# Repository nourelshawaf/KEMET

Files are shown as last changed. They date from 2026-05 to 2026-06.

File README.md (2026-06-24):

# KEMET — Autonomous Maze-Solving Robot

> Embedded C++ · ESP32 + Raspberry Pi Pico · RFID navigation · Encoder-based motor control

Built for the **Óbuda University Labyrinth Competition**. KEMET navigates a maze fully autonomously — no remote control, no external compute. It reads RFID tags at intersections, drives between walls using IR and ToF sensors, and executes turns with encoder-closed-loop feedback.

---

## Demo

> Video coming after first successful maze run.
> 
> Phase 1 preview: encoder-based straight driving + 90° pivot calibration sequence (Straight → Right → Right → Left → Left, repeating).

---

## What It Does

| Capability | Implementation |
|---|---|
| Navigate maze intersections | RC522 RFID reader decodes `LEFT` / `RIGHT` / `DEAD END` tags |
| Drive straight without drift | Encoder pulse comparison between left and right wheel; software trim |
| Execute accurate 90° turns | Encoder-counted pivot; separate left/right calibration constants |
| Detect walls | VL53L1X ToF (front) + 4× Sharp IR (sides) |
| Stop before hitting walls | Front ToF threshold at 150 mm |
| Distributed control | ESP32 handles sensing + logic; Pico handles motors over UART |

---

## Architecture

```
┌─────────────────────────────────┐     UART 115200     ┌──────────────────────┐
│            ESP32                │ ─── "FWD\n" ──────► │   Raspberry Pi Pico  │
│  • RFID (RC522, SPI)            │ ◄── "OK\n" ──────── │  • PWM motor drive   │
│  • ToF wall sensor (VL53L1X)    │                      │  • Encoder counting  │
│  • 4× Sharp IR (analog ADC)     │                      │  • 90° pivot control │
│  • Maze graph + path logic      │                      │  • Drift correction  │
└─────────────────────────────────┘                      └──────────────────────┘
         │                                                        │
         └───────────── TB6612FNG motor driver ◄──────────────────┘
                              │
                    Left motor · Right motor
                   (HC-89 encoders, 35 PPR)
```

**Power:** 2S Li-ion → main switch → buck converter (5 V logic) + direct to motor rail (7.2–8.4 V)

---

## Hardware

| Component | Part |
|---|---|
| Navigation controller | ESP32 (ESP-WROOM-32) |
| Motor controller | Raspberry Pi Pico |
| Motor driver | TB6612FNG |
| Motors | 2× DC gear motors, Ø 37 mm wheels |
| Wheel encoders | 2× HC-89 optical (35 pulses/rev, measured) |
| RFID reader | RC522 — **3.3 V only** |
| Front distance | VL53L1X Time-of-Flight |
| Side distance | 4× Sharp GP2Y0A51SK0F analog IR |
| Power | 2S Li-ion + step-down buck converter |

**Competition constraint:** robot must fit inside `280 × 280 × 150 mm`, operate with no external communication.

---

## Repository Structure

```
KEMET/
├── Code/
│   ├── Pico/motor_control/          ← Phase 1: encoder-based motor calibration (.ino)
│   └── ESP32-mapper/INCLUDE/        ← Maze graph types, sensor manager, pin config (.h)
├── Hardware/
│   ├── wiring_diagrams/             ← Full pin-to-pin tables for V1 and V2
│   ├── schematics/                  ← EasyEDA schematic JSON + generator script
│   └── bill_of_materials.md
├── Docs/
│   ├── system_architecture.md
│   ├── motor_control.md
│   ├── rfid_navigation.md
│   ├── calibration.md
│   ├── wall_following.md
│   ├── troubleshooting.md
│   └── prototypes/prototype_v1.md · prototype_v2.md
├── Tests/
│   ├── turn_tests/
│   ├── straight_line_tests/
│   └── ...
└── Media/photos/
```

---

## How to Run (Phase 1 — Motor Calibration)

**Hardware required:** Raspberry Pi Pico + TB6612FNG + 2 motors + 2 HC-89 encoders. No ESP32 needed for Phase 1.

```bash
# 1. Open Arduino IDE
# 2. Board: Raspberry Pi Pico (arduino-pico core)
# 3. Flash:
Code/Pico/motor_control/phase1_motor_calibration.ino

# 4. Open Serial Monitor at 115200 baud
# Robot runs: Straight → Right → Right → Left → Left, then repeats
```

**Key constants to tune** (top of the sketch):

```cpp
static const int BASE_PWM        = 160;  // straight speed
static const int TURN_PWM        = 130;  // turn speed
static const int STRAIGHT_PULSES =  70;  // ~23 cm distance
static const int TURN_90_PULSES  =  28;  // pulses for 90° pivot — tune this
```

See [`Docs/calibration.md`](Docs/calibration.md) for the full procedure.

---

## Development Status

| Phase | Status | Description |
|---|---|---|
| 1 — Motor calibration | **In progress** | Encoder-based straight + 90° pivot on Pico alone |
| 2 — UART integration | Planned | ESP32 sends movement commands to Pico |
| 3 — Wall detection | Planned | Front ToF stops robot before hitting walls |
| 4 — RFID navigation | Planned | ESP32 reads tags and relays turn commands |
| 5 — Maze mapping | Planned | Graph-based path memory + second-run optimisation |

---

## Documentation

- [System Architecture](Docs/system_architecture.md)
- [Motor Control](Docs/motor_control.md)
- [Calibration](Docs/calibration.md)
- [RFID Navigation](Docs/rfid_navigation.md)
- [Wall Following](Docs/wall_following.md)
- [Hardware Design](Docs/hardware_design.md)
- [Electronics & Power](Docs/electronics_power_system.md)
- [Competition Rules](Docs/competition_rules_summary.md)
- [Testing Protocol](Docs/testing_protocol.md)
- [Troubleshooting](Docs/troubleshooting.md)
- [Prototype V2](Docs/prototypes/prototype_v2.md)

---

## Prototype Photos

Prototype V2 top view
*Prototype V2 — ESP32, Pico, RC522, HC-89 encoders, buck converter, and 2S Li-ion battery integrated on chassis.*

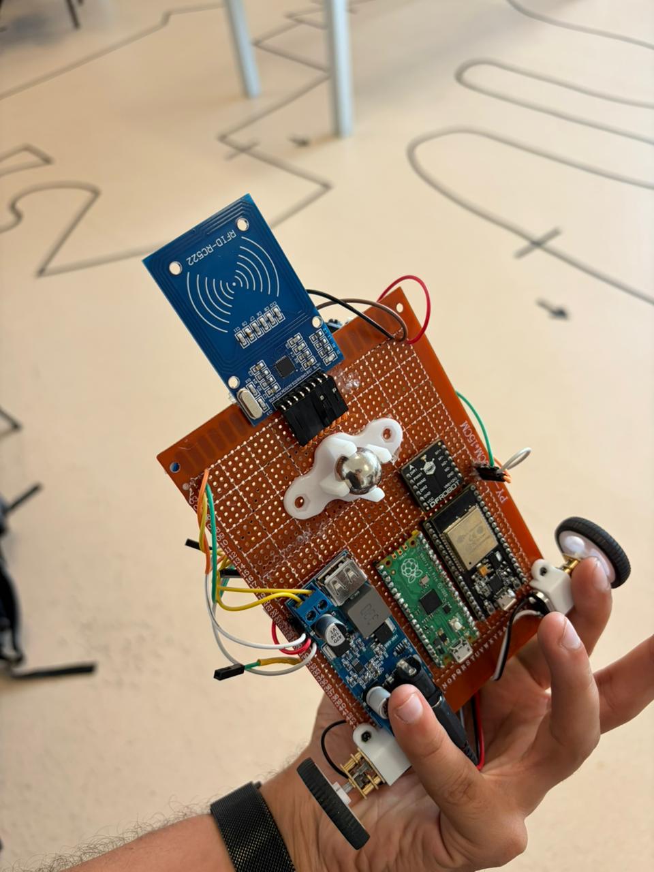
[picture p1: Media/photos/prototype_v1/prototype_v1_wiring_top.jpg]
Prototype V1 wiring

*Prototype V1 — full wiring integration stage.*

---

## Team

KEMET Maze Robot Team — Óbuda University

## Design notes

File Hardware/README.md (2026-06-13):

# Hardware

## Current Prototype Version

**Prototype V2** — see [`Docs/prototypes/prototype_v2.md`](../Docs/prototypes/prototype_v2.md)

## Files

| File | Description |
|---|---|
| `bill_of_materials.md` | Full component list |
| `wiring_diagrams/KEMET_V1_Wiring_Table.md` | Pin-to-pin wiring table (V1) |
| `wiring_diagrams/prototype_v2_pin_map.md` | Pin map for Prototype V2 |
| `schematics/KEMET_V1_Schematic.json` | EasyEDA schematic (import directly) |
| `schematics/generate_schematic.py` | Script to regenerate JSON from source |

## Critical Electrical Rules

1. **RC522 is 3.3 V ONLY.** Connecting to 5 V permanently destroys the chip.
2. **ESP32 and Pico must share a common GND.** A missing GND reference causes erratic behaviour.
3. **TB6612 VM must connect to the battery rail, NOT the buck converter output.** Motor current will overdraw the buck.
4. **TB6612 VCC must connect to Pico 3V3, NOT the 5 V rail.** Logic supply must match Pico drive voltage.
5. **All Sharp IR sensors need decoupling capacitors** (10 µF + 0.1 µF per sensor) to suppress motor switching noise on ADC reads.
6. **Buck converter output must be verified at 5.00 V ±0.1 V** before connecting any board.

## Prototype History

- [Prototype V1](../Docs/prototypes/prototype_v1.md)
- [Prototype V2](../Docs/prototypes/prototype_v2.md)

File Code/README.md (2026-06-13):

# Code

## Structure

| Folder | Board | Status |
|---|---|---|
| `Pico/motor_control/` | Raspberry Pi Pico | Phase 1 — in progress |
| `Pico/encoder_tests/` | Raspberry Pi Pico | Planned |
| `Pico/pid_speed_control/` | Raspberry Pi Pico | Planned |
| `ESP32/rfid_reader/` | ESP32 | Planned |
| `ESP32/maze_logic/` | ESP32 | Planned |
| `ESP32/sensor_tests/` | ESP32 | Planned |
| `integration/esp32_pico_uart/` | Both | Planned |

## ESP32

Handles RFID reading, ToF sensing, IR wall sensing, maze state machine, and high-level navigation decisions. Sends ASCII movement commands to the Pico over UART.

## Pico

Handles PWM generation, encoder pulse counting, straight-line drift correction, and 90° pivot execution. Replies `OK\n` over UART when a movement completes.

## Flashing Order

1. Flash `Pico/motor_control/phase1_motor_calibration.ino` to the Pico.
2. Open Serial Monitor at 115200 baud.
3. Test encoder counting and motor direction.
4. Calibrate `TURN_90_PULSES` per surface.
5. Flash ESP32 RFID/navigation code (Phase 4).
6. Test UART command round-trip between ESP32 and Pico.

## IDE Setup

- Board for Pico: **Raspberry Pi Pico** (Arduino-Pico core)
- Board for ESP32: **ESP32 Dev Module** (ESP32 Arduino core)
- Baud rate for all Serial Monitor: **115200**

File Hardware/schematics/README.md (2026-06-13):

# KEMET Robot V1 — Schematic Files

This folder contains the full wiring architecture schematic for **KEMET Prototype V1**,
an autonomous maze-solving robot.

---

## Files

| File | Purpose |
|---|---|
| `KEMET_V1_Schematic.json` | EasyEDA Standard Edition schematic (import directly) |
| `generate_schematic.py` | Python script that regenerates the JSON from source |
| `KEMET_V1_Wiring_Table.md` | Complete pin-to-pin wiring table with net names |
| `README.md` | This file |

---

## How to Open in EasyEDA Standard Edition

### Method 1 — Direct file open (recommended)

1. Open [EasyEDA Standard Edition](https://easyeda.com/editor) in your browser,
   or the desktop app.
2. Click **File → Open** (or press `Ctrl+O`).
3. Select `KEMET_V1_Schematic.json`.
4. The schematic opens immediately — no library installation required.

> **Note:** EasyEDA Standard Edition is the free web/desktop tool at easyeda.com.
> Do **not** use EasyEDA Pro — the JSON format is different and not compatible.

### Method 2 — Import into an existing project

1. Open your project in EasyEDA Standard.
2. Right-click the project in the left panel → **Import**.
3. Select `KEMET_V1_Schematic.json`.

---

## How to Regenerate the JSON

If you edit `generate_schematic.py` (e.g. to add a component or change a layout),
re-run it to produce a fresh `KEMET_V1_Schematic.json`:

```bash
cd KEMET/schematics
python generate_schematic.py
```

Requires Python 3.6+ with no external dependencies.

---

## Schematic Layout

```
+------------------+  +------------------------------------------+
|  1. POWER        |  |        5. SENSOR SUBSYSTEM                |
|  2S Li-ion       |  |  4x Sharp IR | VL53L1X ToF | RC522 RFID  |
|  Buck 5V reg     |  |                                           |
+------------------+  +------------------------------------------+
+------------------+      +--------------------+
|  2. ESP32        |      |  6. UART BRIDGE     |
|  Navigation/     |      |  ESP32 ↔ Pico       |
|  Sensing         |      +--------------------+
+------------------+
+------------------+  +------------------+  +------------------+
|  3. Pico         |  |  4. TB6612FNG    |  |  7. MOTORS        |
|  Motor Control   |  |  Motor Driver    |  |  2x N20 12V      |
+------------------+  +------------------+  +------------------+

+------------------------------------------------------------------+
|  WARNING NOTES                                                   |
+------------------------------------------------------------------+
|  TITLE BLOCK                                                     |
+------------------------------------------------------------------+
```

---

## Key Design Decisions

| Decision | Reason |
|---|---|
| ESP32 handles all sensors | ESP32 has hardware SPI, I2C, and multiple ADC channels |
| Pico handles all motors | Dedicated PWM hardware; keeps latency predictable |
| UART inter-board link | Simple, reliable; sufficient bandwidth for V1 commands |
| 5 V for Sharp IR sensors | Sensors spec'd for 4.5–5.5 V; better range accuracy at 5 V |
| 3.3 V for RC522 | RC522 is a 3.3 V device; 5 V destroys it |
| Battery → TB6612 VM direct | Motor voltage should not pass through the 5 V buck |
| Pico 3V3 → TB6612 VCC | TB6612 logic supply must match Pico's drive voltage |
| No encoders (V1) | Simplifies wiring; wall-correction via IR sensors instead |

---

## Prototype V1 Limitations

- **No wheel encoders** — speed/position is not measured
- **Open-loop motor control** — corrected by IR sensor wall distance only
- **No STBY control** — TB6612 STBY pin should be tied permanently HIGH (3.3 V)
- **No fault detection** — TB6612 fault output not connected

---

## Schematic Shape Types Used

EasyEDA Standard Edition shape types present in the JSON:

| Type | Purpose |
|---|---|
| `POLYLINE` | Non-electrical module outlines and title bars |
| `ANNOTATION` | All text labels, pin names, warnings |
| `NETLABEL` | Electrical net connections (same name = same net) |
| `WIRE` | Electrical pin stub wires |

> Electrical connections are made entirely through **matching NETLABEL names**.
> No long crossing wires — the schematic is readable at any zoom level.

---

## Safety Warnings

> **RC522:** 3.3 V ONLY — connecting to 5 V will permanently destroy the chip.

> **TB6612 VM vs VCC:** VM is the motor power rail (battery voltage).
> VCC is the logic supply (3.3 V from Pico). They must NOT be swapped.

> **Buck converter:** Always verify 5.00 V output before connecting boards.

> **Common GND:** All subsystems (ESP32, Pico, TB6612, all sensors, battery negative)
> must share one common ground reference.

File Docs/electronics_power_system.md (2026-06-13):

# Electronics & Power System

## Purpose

Documents the power subsystem design, voltage rails, current budgets, and wiring safety rules.

## Hardware Used

- 2S Li-ion battery (~7.2–8.4 V nominal range)
- Main power switch (inline, 20 AWG minimum)
- Step-down (buck) converter — output: 5.00 V regulated
- TB6612FNG VM rail (motor power, direct from battery)

## Voltage Rails

| Rail | Source | Voltage | Consumers |
|---|---|---|---|
| `+BATT` | Battery through switch | 7.2–8.4 V | TB6612 VM only |
| `+5V` | Buck converter output | 5.00 V ±0.1 V | ESP32 VIN, Pico VSYS, Sharp IR VCC |
| `+3V3_ESP` | ESP32 internal regulator | 3.3 V | RC522 VCC |
| `+3V3_PICO` | Pico internal regulator | 3.3 V | TB6612 VCC (logic supply) |
| `GND` | Battery negative | 0 V | All modules, common bus |

## Pre-Power Checklist

- [ ] Buck output measured = **5.00 V ±0.1 V** before connecting any board
- [ ] All GNDs verified continuous to battery negative (multimeter continuity)
- [ ] RC522 VCC confirmed on ESP32 3V3 — NOT the 5 V rail
- [ ] TB6612 VM confirmed on battery rail — NOT buck output
- [ ] TB6612 VCC confirmed on Pico 3V3 — NOT 5 V rail
- [ ] TB6612 STBY pin tied HIGH (3.3 V or VCC)
- [ ] All Sharp IR decoupling capacitors installed (10 µF + 0.1 µF per sensor)
- [ ] UART TX/RX cross-connected (ESP32 TX → Pico RX, Pico TX → ESP32 RX)

## Decoupling Requirements

Each Sharp IR sensor requires two capacitors placed close to the sensor:
- 10 µF electrolytic: VCC to GND
- 0.1 µF ceramic: VCC to GND (in parallel)

Without decoupling, motor switching noise corrupts ADC readings.

## Safety Rules

> **RC522:** 3.3 V ONLY. 5 V permanently destroys the chip.

> **TB6612 VM vs VCC:** VM is motor power (battery voltage). VCC is logic supply (3.3 V). Do not swap.

> **Buck converter:** Never power boards before verifying 5.00 V output.

> **Common GND:** All subsystems must share one GND reference. A missing GND causes erratic or non-functional behaviour.

## Current Status

Power system is wired on Prototype V1. Buck output verified at 5 V. Full load test not yet performed.

## Known Problems

- Motor current draw under stall not measured yet. Buck converter rating must be verified against actual motor current.

## Next Steps

- Measure motor current draw at BASE_PWM = 160 under loaded conditions.
- Add main fuse inline with battery positive.

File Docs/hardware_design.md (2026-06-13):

# Hardware Design

## Purpose

Documents the physical hardware choices, component selection rationale, and prototype V1 configuration.

## Hardware Used

| Component | Part | Notes |
|---|---|---|
| Navigation controller | ESP32 (ESP-WROOM-32) | Hardware SPI, I2C, multiple ADC channels |
| Motor controller | Raspberry Pi Pico | Dedicated PWM hardware; predictable timing |
| Motor driver | TB6612FNG | Dual DC motor driver, 3.3 V logic compatible |
| Motors | 2× DC gear motors | Wheel Ø = 37 mm |
| Encoders | 2× HC-89 optical sensors | 35 pulses per wheel revolution (measured) |
| RFID reader | RC522 | 3.3 V only — never connect to 5 V |
| Front distance | VL53L1X ToF | I2C, Adafruit library |
| Side distance | 4× Sharp GP2Y0A51SK0F | Analog output, 5 V supply |
| Power | 2S Li-ion + buck converter | Buck → 5 V logic; battery direct → motor rail |

## Chassis

- Prototype V1 is assembled on a custom chassis.
- Robot width must remain under 280 mm (competition constraint).
- Wheel-to-wheel distance (L): 115 mm (measured, used in turn calculations).

## Power Architecture

```
2S Li-ion Battery
    │
    ├── Main power switch
    │       │
    │       ├── Buck converter → 5 V regulated
    │       │       ├── ESP32 VIN
    │       │       ├── Pico VSYS
    │       │       └── Sharp IR VCC (×4)
    │       │
    │       └── TB6612 VM (motor power rail, ~7.2–8.4 V)
    │
    └── Common GND bus (all modules)
```

## Key Design Decisions

| Decision | Reason |
|---|---|
| ESP32 handles sensing | Hardware SPI + I2C + ADC on one chip |
| Pico handles motors | Hardware PWM; no interrupt conflicts with sensing |
| UART inter-board link | Simple, 3.3 V native, sufficient bandwidth |
| 5 V for Sharp IR | Sharp sensors spec'd at 4.5–5.5 V; better range accuracy |
| 3.3 V for RC522 | RC522 is 3.3 V only; 5 V destroys it permanently |
| Battery direct to TB6612 VM | Motor current must not pass through the buck converter |
| Pico 3.3 V to TB6612 VCC | TB6612 logic must match Pico drive voltage |

## Prototype V1 Limitations

- Right motor wires are physically reversed so both channels share the same direction logic in firmware.
- TB6612 STBY pin is tied permanently HIGH (no software control of enable/disable).
- No fault detection on TB6612.

## Current Status

Prototype V1 is assembled. Motor control (Phase 1) is in progress. Sensors not yet integrated.

## Known Problems

- Sharp IR sensors require decoupling capacitors (10 µF + 0.1 µF per sensor) to avoid noisy ADC readings.
- VL53L1X breakout board regulator must be verified before powering from 5 V.

## Next Steps

- Verify VL53L1X I2C addressing on ESP32.
- Mount all four Sharp IR sensors and check ADC readings.
- Add RC522 and test SPI communication with ESP32.

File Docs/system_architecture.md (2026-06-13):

# System Architecture

## Purpose

Defines how the ESP32 and Raspberry Pi Pico divide responsibilities and communicate, and how all sensors and actuators connect to each controller.

## Design Decision: Dual-Controller Split

| Controller | Responsibility |
|---|---|
| ESP32 | RFID reading, ToF sensing, IR wall sensing, maze logic, navigation decisions |
| Pico | PWM generation, encoder counting, motor speed control, movement execution |

The split keeps real-time motor control on a dedicated microcontroller (Pico) while the ESP32 handles slower, higher-level navigation logic. UART connects them at 115200 baud.

## Communication Protocol (ESP32 → Pico)

Commands are ASCII strings terminated with `\n`:

| Command | Meaning |
|---|---|
| `FWD\n` | Drive forward one corridor length |
| `LEFT_90\n` | Pivot left 90° |
| `RIGHT_90\n` | Pivot right 90° |
| `STOP\n` | Stop immediately |
| `U_TURN\n` | Pivot 180° (planned) |

The Pico executes the movement and sends back `OK\n` when complete.

## Data Flow

```
RFID card read
    → ESP32 decodes command
    → ESP32 sends movement string over UART
    → Pico drives motors, counts encoder pulses
    → Pico sends OK
    → ESP32 checks wall sensors and plans next move
```

## Hardware Connections Summary

See [`Hardware/wiring_diagrams/KEMET_V1_Wiring_Table.md`](../Hardware/wiring_diagrams/KEMET_V1_Wiring_Table.md) for the full pin-to-pin table.

## Current Status

Phase 1 (Pico standalone motor control) is in progress. UART integration between ESP32 and Pico is Phase 2.

## Known Problems

- Communication protocol is not yet implemented (Phase 2).
- Error handling for lost UART bytes not designed yet.

## Next Steps

- Implement UART send/receive on both boards.
- Define ACK/NACK protocol for command confirmation.
- Test latency of command round-trip.

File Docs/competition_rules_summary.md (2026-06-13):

# Competition Rules Summary

Only the rules that directly affect engineering decisions are listed here.

## Robot Size Constraint

- Maximum: `280 × 280 × 150 mm`
- The robot must fit through the maze corridor at any heading.

## Autonomy Requirement

- The robot must move autonomously after the start signal.
- No remote control, no wireless commands during the run.
- No external computing — all logic runs on the robot.

## Navigation Markers

RFID tags (or pictograms) are placed at intersections and decision points.

| Marker | Robot Action |
|---|---|
| `START` | Begin run |
| `STOP` | End run, stop robot |
| `LEFT` | Turn left at next intersection |
| `RIGHT` | Turn right at next intersection |
| `DEAD END` | U-turn |

The robot must be able to read the marker and execute the corresponding movement.

## Maze Physical Dimensions

- Corridor width: `28.5 ± 1 cm`
- Wall height: `15 cm`
- Wall thickness: `15 mm`
- Floor material: OSB

## Qualification Tasks

1. **Straight track** — robot must drive a straight corridor without hitting walls.
2. **Curved track** — robot must navigate a curved corridor, following the wall.

Both qualification tasks must be completed before the main maze run.

## Engineering Implications

| Rule | Impact on Design |
|---|---|
| 280 mm max width | Robot chassis must be narrower than corridor; leaves ~4–5 cm margin |
| Autonomous only | No Bluetooth/WiFi during run; ESP32 Wi-Fi kept off |
| RFID navigation | RC522 reader required; reading must be reliable at driving speed |
| Straight + curve quals | Wall-following must work before maze logic is needed |
| Dead end handling | U-turn (180°) movement must be implemented and calibrated |

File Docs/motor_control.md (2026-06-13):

# Motor Control

## Purpose

The Pico controls two DC gear motors through the TB6612FNG motor driver. It receives high-level ASCII movement commands from the ESP32 over UART and handles low-level PWM generation, encoder pulse counting, straight-line correction, and 90° pivot calibration.

## Hardware Used

- Raspberry Pi Pico
- TB6612FNG dual motor driver
- 2× DC gear motors (Ø 37 mm wheels)
- 2× HC-89 optical encoders (35 pulses per full wheel revolution, measured)

## Pin Connections

| Pico GP | TB6612 Pin | Function |
|---|---|---|
| GP2 | PWMA | Left motor speed (PWM) |
| GP3 | AIN (DIR) | Left motor direction |
| GP4 | PWMB | Right motor speed (PWM) |
| GP5 | BIN (DIR) | Right motor direction |
| 3V3(OUT) | VCC | TB6612 logic supply |
| GND | GND | Common ground |

| Pico GP | Encoder |
|---|---|
| GP6 | Left HC-89 OUT |
| GP7 | Right HC-89 OUT |

> TB6612 STBY must be tied HIGH to enable the driver.
> Right motor wires are physically reversed so both channels share the same direction logic.

## Movement Commands

| Command | Action |
|---|---|
| `FWD` | Drive forward — straight, encoder-controlled |
| `LEFT_90` | Pivot left 90° using encoder pulse count |
| `RIGHT_90` | Pivot right 90° using encoder pulse count |
| `STOP` | Stop all motors |
| `U_TURN` | Planned — 180° pivot |
| `LEFT_45` | Planned |
| `RIGHT_45` | Planned |

## Software Logic

**Straight movement:**
Both motors run at `BASE_PWM`. Encoder counts are compared every loop; if one wheel is ahead by more than 2 pulses, it is slowed by a trim offset until both counts re-align. Movement stops when the average pulse count reaches `STRAIGHT_PULSES`.

**90° pivot:**
One motor runs forward, the other backward, both at `TURN_PWM`. Movement stops when the average pulse count across both wheels reaches `TURN_90_PULSES`. Both wheels move to reduce wheel slip vs. a single-wheel pivot.

## Calibration Parameters

| Parameter | Value |
|---|---|
| Wheel diameter | 37 mm |
| Wheel-to-wheel distance (L) | 115 mm |
| Encoder pulses per revolution | 35 (HC-89, RISING edge) |
| BASE_PWM | 160 |
| TURN_PWM | 130 |
| STRAIGHT_PULSES | 70 (~23 cm) |
| TURN_90_PULSES | 28 (calculated: 27.2, tune per floor) |

Calculated starting point for `TURN_90_PULSES`:
```
Wheel circumference  = π × 37 mm = 116.24 mm
Arc for 90° pivot    = π × 115 mm / 4 = 90.32 mm
Revolutions needed   = 90.32 / 116.24 = 0.777
Pulse target         = 0.777 × 35 = 27.2 → start at 28
```

## Current Status

Phase 1 in progress. Straight movement implemented. Encoder-based turns implemented. Calibration values not yet locked.

## Known Problems

- Turn angle error accumulates after multiple turns. After two rights and two lefts, heading may have drifted.
- Left and right turns may need separate calibration values due to chassis asymmetry.
- Mechanical wheel slip on smooth floors increases turn error.
- Drift correction trim value (currently 15 PWM units) not yet verified on all floor surfaces.

## Next Steps

- Lock `TURN_90_PULSES` per floor surface.
- Run 4-turn heading-return test and measure accumulated error.
- Store separate left/right correction constants if turns are asymmetric.
- Add closed-loop heading correction using encoder difference or IMU in a later phase.

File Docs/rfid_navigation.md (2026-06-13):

# RFID Navigation

## Purpose

The ESP32 reads RC522 RFID tags placed at maze intersections. Each tag encodes a navigation command. The ESP32 decodes the UID, maps it to a command, and relays the movement instruction to the Pico over UART.

## Hardware Used

- ESP32 (ESP-WROOM-32)
- RC522 RFID reader module (3.3 V only)
- RFID tags/cards with unique UIDs

## Pin Connections

| ESP32 GPIO | RC522 Pin | Net |
|---|---|-----|
| GPIO5 | SDA / SS | RFID_SS |
| GPIO18 | SCK | SPI_SCK |
| GPIO23 | MOSI | SPI_MOSI |
| GPIO19 | MISO | SPI_MISO |
| GPIO4 | RST | RFID_RST |
| 3V3 | 3.3V | Power |
| GND | GND | GND |

> RC522 must be powered from 3.3 V ONLY. 5 V permanently destroys the chip.

## UID-to-Command Mapping

UIDs must be measured from the actual cards used and stored in firmware:

| UID | Command | Robot Action |
|-----|---|---|
| TBD | START | Begin run |
| TBD | STOP | End run |
| TBD | LEFT | Turn left |
| TBD | RIGHT | Turn right |
| TBD | DEAD END | U-turn |

## Software Logic

1. Poll for card presence using MFRC522 library `PICC_IsNewCardPresent()`.
2. Read UID with `PICC_ReadCardSerial()`.
3. Look up UID in the command table.
4. Send the corresponding command string to Pico over UART.
5. Wait for `OK\n` response from Pico before reading next card.

## Current Status

Not yet implemented. Phase 4 work. RC522 hardware is connected but code is not written.

## Known Problems

- UID table is empty — cards have not been measured yet.
- Reading speed at driving velocity is unknown; may need robot to slow down before tag.

## Next Steps

- Read and print UIDs for each navigation card.
- Build the UID → command lookup table in firmware.
- Test RFID reading reliability while stationary.
- Test reading while moving at Phase 1 drive speed.

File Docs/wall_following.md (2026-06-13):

# Wall Following

## Purpose

The robot uses four Sharp IR sensors and one front-facing ToF sensor to detect walls, correct lateral drift, and stop before hitting obstacles.

## Hardware Used

- 4× Sharp GP2Y0A51SK0F analog IR sensors (left outer, left inner, right inner, right outer)
- VL53L1X Time-of-Flight sensor (front, I2C)
- ESP32 ADC (GPIO34, GPIO35, GPIO36, GPIO39)

## Pin Connections

| ESP32 GPIO | Sensor | Net |
|---|---|-----|
| GPIO34 | Left Outer IR OUT | IR_LO |
| GPIO35 | Left Inner IR OUT | IR_LI |
| GPIO36 | Right Inner IR OUT | IR_RI |
| GPIO39 | Right Outer IR OUT | IR_RO |
| GPIO21 | VL53L1X SDA | I2C_SDA |
| GPIO22 | VL53L1X SCL | I2C_SCL |

All Sharp IR VCC → +5V rail. All Sharp IR GND → common GND.
Decoupling required: 10 µF + 0.1 µF per sensor.

## Software Logic

**Lateral correction (planned):**
- Read left and right inner IR distance values.
- Compute error: `error = IR_LI - IR_RI`.
- Send trim command to Pico if error exceeds threshold: slow down one motor slightly.

**Front wall stop (planned):**
- Read VL53L1X distance continuously while moving.
- If distance < `WALL_STOP_MM`, send `STOP` to Pico immediately.
- This prevents the robot from hitting a dead-end wall before RFID detects DEAD END.

**Corridor detection (planned):**
- If both left IR and right IR read near-wall distances, robot is in a corridor — use lateral correction.
- If one side reads open, robot is at an intersection — use RFID command.

## Calibration

- Wall distance threshold `WALL_STOP_MM`: TBD (depends on corridor width and sensor mounting position).
- IR balance point (desired left/right difference = 0): depends on robot centering in corridor.

## Current Status

Not implemented. Phase 3 (ToF stop) and later (IR wall following) are planned.

## Known Problems

- Sharp IR sensors have nonlinear output voltage curves. ADC values must be mapped to mm using the datasheet curve or empirical calibration.
- ESP32 ADC has known non-linearity at the high end (>3.1 V). Use voltage dividers or characterise the ADC before relying on distance values.

## Next Steps

- Wire all four IR sensors and read raw ADC values.
- Map ADC voltage to distance using the Sharp datasheet characteristic curve.
- Implement front wall stop using VL53L1X.
- Implement lateral correction loop.

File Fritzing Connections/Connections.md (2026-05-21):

## Final Connection Table

| Subsystem | From | To | Purpose / Notes |
|---|---|---|---|
| Power | Battery + | TB6612 VM | Motor power input |
| Power | Battery + | Buck converter IN+ | Input to 5V regulator |
| Power | Battery - | Common GND | Main ground |
| Power | Battery - | Buck converter IN- | Buck converter ground |
| Power | 5V buck OUT+ | ESP32 VIN / 5V | ESP32 power |
| Power | 5V buck OUT+ | Pico VSYS | Pico power |
| Power | 5V buck OUT+ | Sharp IR VCC | Power for all 4 IR sensors |
| Power | 5V buck OUT+ | VL53L1X VIN | Only if the module supports 5V |
| Power | 5V buck OUT- | Common GND | 5V rail ground |
| Power | Pico 3V3 | TB6612 VCC | TB6612 logic power |
| Power | ESP32 3V3 | RC522 VCC | RC522 must use 3.3V only |
| Ground | Common GND | ESP32 GND | Shared ground |
| Ground | Common GND | Pico GND | Shared ground |
| Ground | Common GND | TB6612 GND | Shared ground |
| Ground | Common GND | Sharp IR GND | Shared ground |
| Ground | Common GND | VL53L1X GND | Shared ground |
| Ground | Common GND | RC522 GND | Shared ground |
| Pico to TB6612 | Pico GP2 | TB6612 PWM1 | Motor 1 speed control |
| Pico to TB6612 | Pico GP3 | TB6612 DIR1 | Motor 1 direction |
| Pico to TB6612 | Pico GP4 | TB6612 PWM2 | Motor 2 speed control |
| Pico to TB6612 | Pico GP5 | TB6612 DIR2 | Motor 2 direction |
| Motor Output | TB6612 M1+ / M1- | Left N20 motor | Left motor output |
| Motor Output | TB6612 M2+ / M2- | Right N20 motor | Right motor output |
| ESP32 IR Sensors | IR Left Outer OUT | ESP32 GPIO34 | Analog input |
| ESP32 IR Sensors | IR Left Inner OUT | ESP32 GPIO35 | Analog input |
| ESP32 IR Sensors | IR Right Inner OUT | ESP32 GPIO36 | Analog input |
| ESP32 IR Sensors | IR Right Outer OUT | ESP32 GPIO39 | Analog input |
| ESP32 ToF | VL53L1X SDA | ESP32 GPIO21 | I2C data |
| ESP32 ToF | VL53L1X SCL | ESP32 GPIO22 | I2C clock |
| ESP32 RFID | RC522 SS / SDA | ESP32 GPIO5 | RFID chip select |
| ESP32 RFID | RC522 SCK | ESP32 GPIO18 | RFID SPI clock |
| ESP32 RFID | RC522 MOSI | ESP32 GPIO23 | RFID SPI MOSI |
| ESP32 RFID | RC522 MISO | ESP32 GPIO19 | RFID SPI MISO |
| ESP32 RFID | RC522 RST | ESP32 GPIO4 | RFID reset |
| ESP32 to Pico SPI | ESP32 GPIO14 | Pico GP18 | SPI SCK |
| ESP32 to Pico SPI | ESP32 GPIO13 | Pico GP19 | SPI MOSI |
| ESP32 to Pico SPI | ESP32 GPIO32 | Pico GP16 | SPI MISO |
| ESP32 to Pico SPI | ESP32 GPIO33 | Pico GP17 | SPI CS / SS |
| ESP32 to Pico SPI | ESP32 GND | Pico GND | Required shared ground |

## Notes

- ESP32 is the **SPI master**.
- Raspberry Pi Pico is the **SPI slave**.
- RC522 uses its own SPI pins on the ESP32.
- Pico uses a separate SPI bus on the ESP32, so there is no pin conflict.
- TB6612 **VM** is motor power.
- TB6612 **VCC** is logic power from Pico **3.3V**.
- RC522 must be powered from **3.3V only**.
- All grounds must be common.
- Start motor testing with low PWM values, around **50–80**, not full speed.
- This is a prototype connector-level wiring plan, not a verified PCB layout.

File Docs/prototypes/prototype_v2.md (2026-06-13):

# Prototype V2

## Overview

Prototype V2 is the current breadboard-based hardware integration version of KEMET. It combines the motor platform, encoder feedback, power system, ESP32/Pico control architecture, RFID reader, and distance sensors into one testable robot body. The primary goal of this version is to validate all subsystems together before moving to soldered protoboard or PCB.

## Main Visible Components

- Raspberry Pi Pico (motor controller, top rear)
- ESP32 (navigation controller, left side)
- RC522 RFID reader (mounted rear/top for tag detection testing)
- 2× HC-89 optical encoder modules (mounted near motor wheels)
- Front-mounted DC-DC power regulation module (buck converter)
- 2-cell Li-ion battery holder (front-bottom)
- Breadboard-based temporary wiring (full chassis width)
- 2WD robot chassis (MDF/laser-cut, yellow wheels)
- Sharp IR sensor visible on right side (wall sensing)

## Changes from Prototype V1

- Full electronics placed on the robot chassis (V1 had partial placement)
- Battery and power converter repositioned to front of chassis
- Encoder sensors mounted and wired to motor shafts
- RFID reader mounted and wired at rear for detection testing
- More sensors integrated into the main breadboard layout

## Current Status

Prototype V2 is suitable for:
- Firmware testing
- Motor and encoder calibration
- RFID detection tests
- Encoder counting verification
- Power system load testing

It is **not yet final competition hardware** because:
- Wiring is temporary breadboard/jumper-based
- Component height not yet verified against 150 mm competition limit
- Full robot dimensions not yet measured
- Wiring is mechanically exposed to vibration during turns

## Known Issues

- Jumper wires may move during turns, causing intermittent encoder or sensor faults.
- Long signal wires routed alongside power wires may pick up motor switching noise.
- Breadboard connections are not reliable under repeated vibration.
- Wiring is difficult to inspect from photos alone — needs a labeled diagram.
- Power wiring not yet separated from signal wiring.

## Required Next Improvements

- [ ] Measure full robot dimensions (L × W × H) against 280 × 280 × 150 mm limit
- [ ] Replace breadboard wiring with soldered protoboard or PCB
- [ ] Add strain relief on battery and motor wires
- [ ] Document exact pin map for this prototype version in `Hardware/wiring_diagrams/prototype_v2_pin_map.md`
- [ ] Add decoupling capacitors to all Sharp IR sensors
- [ ] Separate power and signal wire routing physically

## Photos

Prototype V2 front overview
*Front overview of Prototype V2 showing battery position, front power module, HC-89 encoder sensors, main breadboard wiring, Pico controller, and rear RFID reader placement.*

Prototype V2 top overview
*Top view of Prototype V2 showing component layout and temporary breadboard-based wiring before protoboard cleanup.*

Prototype V2 side power system
*Side view of Prototype V2 showing battery holder, DC-DC converter module, wiring route, and sensor/controller stacking.*

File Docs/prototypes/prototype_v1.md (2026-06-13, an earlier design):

# Prototype V1

## Overview

Prototype V1 was the first fully assembled version of the KEMET robot. It established the core hardware architecture: ESP32 for sensing and navigation, Raspberry Pi Pico for motor control, TB6612FNG motor driver, and breadboard-based wiring.

## Main Components

- Raspberry Pi Pico (motor controller)
- ESP32 (navigation, sensing)
- TB6612FNG motor driver
- 2× DC gear motors (Ø 37 mm wheels)
- 2× HC-89 optical encoders
- 2S Li-ion battery pack
- Buck converter (5 V regulated)
- Breadboard wiring

## Status

Prototype V1 hardware is assembled. Phase 1 firmware (encoder-based motor calibration) is in progress.

## Known Issues

- Wiring is all-breadboard: jumper wires may move during turns and cause intermittent faults.
- No decoupling capacitors installed on Sharp IR sensors yet.
- TB6612 STBY is permanently tied HIGH; no software enable/disable.
- Robot dimensions not yet measured against competition limit (280 × 280 × 150 mm).

## Photos

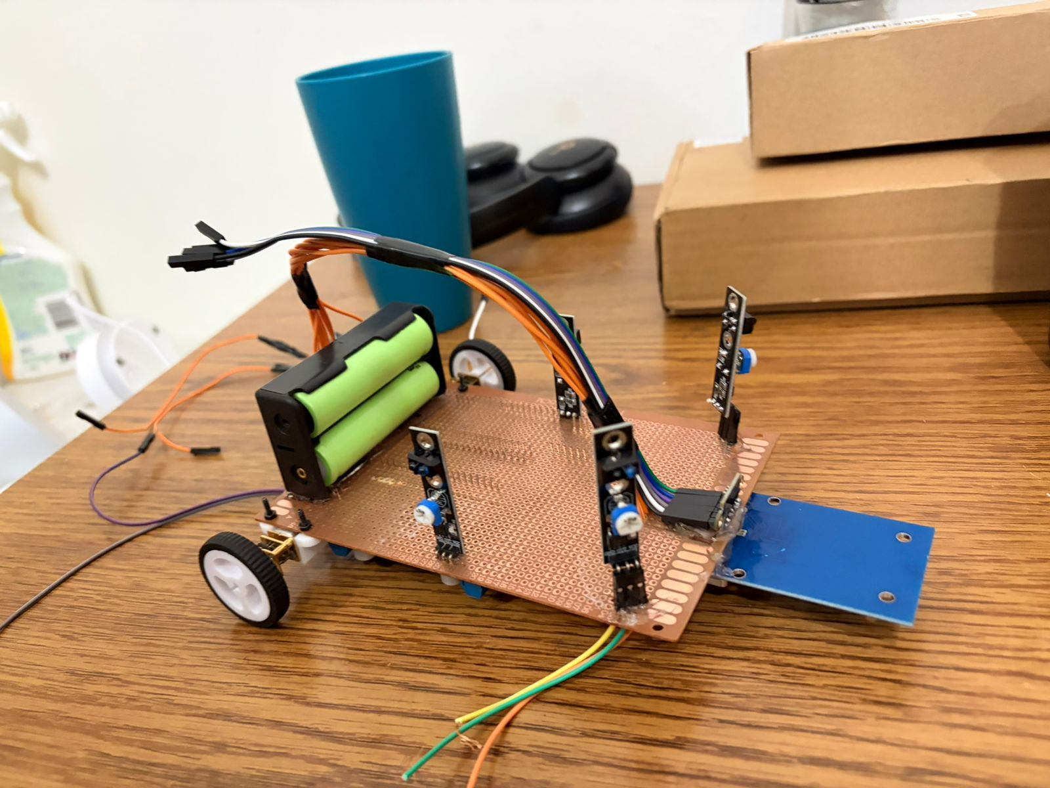
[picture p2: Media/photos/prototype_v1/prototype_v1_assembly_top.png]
Prototype V1 assembly top

*Top view of Prototype V1 showing initial chassis assembly and component placement.*

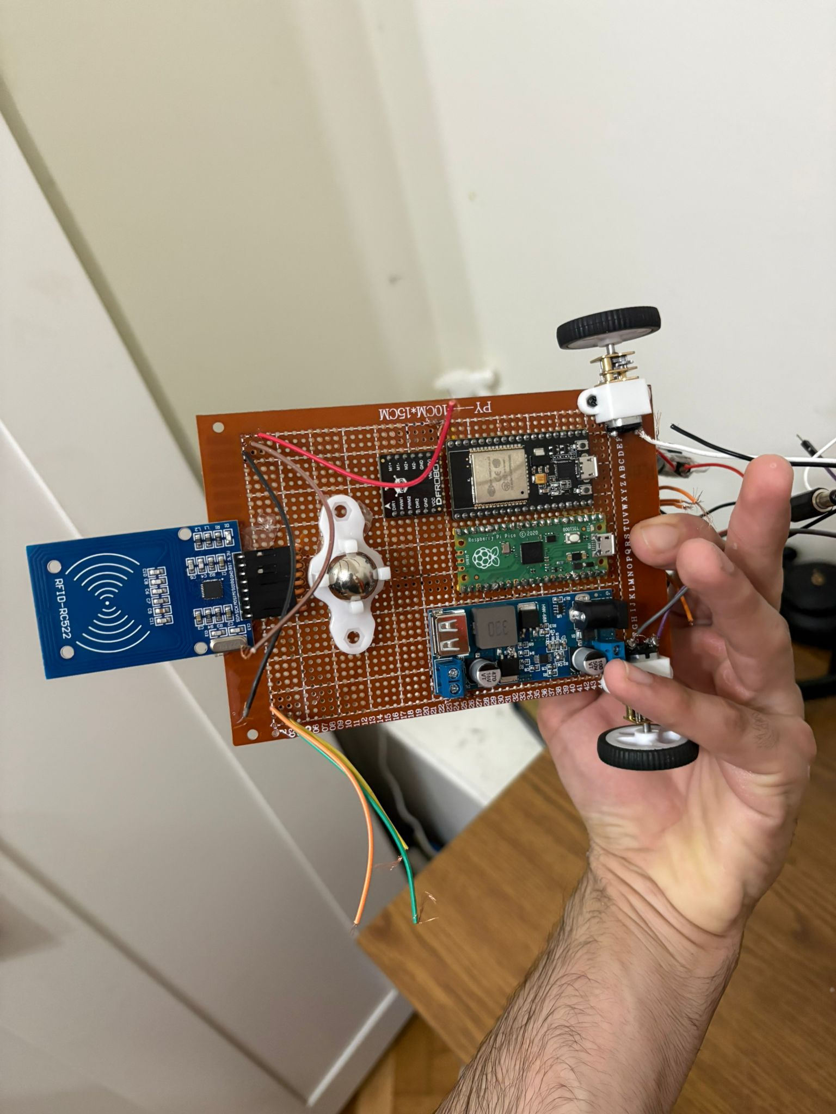
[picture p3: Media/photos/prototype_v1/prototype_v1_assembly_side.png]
Prototype V1 assembly side

*Side view of Prototype V1 showing motor and wheel layout.*

Prototype V1 wiring top
*Top view after wiring integration: ESP32, Pico, breadboard, HC-89 encoders, battery, and power module visible.*

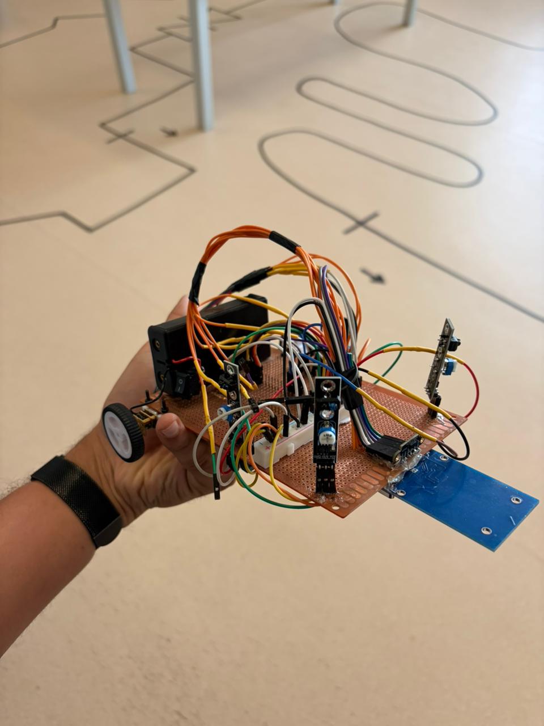
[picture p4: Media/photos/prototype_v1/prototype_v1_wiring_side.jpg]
Prototype V1 wiring side

*Side/rear view after wiring integration showing power system routing.*

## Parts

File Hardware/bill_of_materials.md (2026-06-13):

# Bill of Materials — KEMET Prototype V1

| # | Component | Part Number / Model | Qty | Notes |
|---|---|---|-----|---|
| 1 | Main controller | ESP32 ESP-WROOM-32 | 1 | Navigation, sensing, RFID |
| 2 | Motor controller | Raspberry Pi Pico | 1 | PWM, encoder counting |
| 3 | Motor driver | TB6612FNG breakout | 1 | Dual channel, 3.3 V logic |
| 4 | DC gear motor | N20-style, Ø 37 mm wheel | 2 | |
| 5 | Wheel encoder | HC-89 optical sensor | 2 | 35 pulses/rev measured |
| 6 | RFID reader | RC522 module | 1 | 3.3 V only |
| 7 | Front ToF sensor | VL53L1X breakout | 1 | I2C, front wall detection |
| 8 | Side IR sensor | Sharp GP2Y0A51SK0F | 4 | Analog, 5 V supply |
| 9 | Battery | 2S Li-ion pack | 1 | ~7.2–8.4 V nominal |
| 10 | Buck converter | 5 V step-down module | 1 | Min 2 A rated |
| 11 | Power switch | Inline rocker switch | 1 | 20 AWG rated |
| 12 | Decoupling cap | 10 µF electrolytic | 4 | One per Sharp IR sensor |
| 13 | Decoupling cap | 0.1 µF ceramic | 4 | One per Sharp IR sensor |
| 14 | Wiring | 20 AWG silicone wire | — | Power rails |
| 15 | Wiring | 26–28 AWG signal wire | — | Data lines |

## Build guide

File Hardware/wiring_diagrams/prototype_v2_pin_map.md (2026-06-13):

# Prototype V2 Pin Map

Status: **TBD — fill in from actual hardware before next firmware flash**

Verify each entry against the physical robot before trusting it.

---

## ESP32

| Module | Signal | ESP32 GPIO | Direction | Notes |
|---|---|---|---|---|
| RC522 | SDA/SS | GPIO5 | OUT | RFID chip select |
| RC522 | SCK | GPIO18 | OUT | SPI clock |
| RC522 | MOSI | GPIO23 | OUT | SPI MOSI |
| RC522 | MISO | GPIO19 | IN | SPI MISO |
| RC522 | RST | GPIO4 | OUT | Reset |
| RC522 | 3.3V | 3V3 | PWR | 3.3 V only — never 5 V |
| VL53L1X | SDA | GPIO21 | Bidir | I2C data |
| VL53L1X | SCL | GPIO22 | OUT | I2C clock |
| Sharp IR LO | OUT | GPIO34 | IN | Left outer IR (input-only pin) |
| Sharp IR LI | OUT | GPIO35 | IN | Left inner IR (input-only pin) |
| Sharp IR RI | OUT | GPIO36 | IN | Right inner IR (input-only pin) |
| Sharp IR RO | OUT | GPIO39 | IN | Right outer IR (input-only pin) |
| Pico UART | TX | GPIO17 | OUT | ESP32 → Pico |
| Pico UART | RX | GPIO16 | IN | Pico → ESP32 |

---

## Raspberry Pi Pico

| Module | Signal | Pico GP | Direction | Notes |
|---|---|---|---|---|
| TB6612FNG | PWMA | GP2 | OUT | Left motor speed |
| TB6612FNG | AIN (DIR) | GP3 | OUT | Left motor direction |
| TB6612FNG | PWMB | GP4 | OUT | Right motor speed |
| TB6612FNG | BIN (DIR) | GP5 | OUT | Right motor direction |
| Left HC-89 | OUT | GP6 | IN | Left encoder interrupt |
| Right HC-89 | OUT | GP7 | IN | Right encoder interrupt |
| ESP32 UART | RX | GP1 | IN | Commands from ESP32 |
| ESP32 UART | TX | GP0 | OUT | ACK replies to ESP32 |

---

## TB6612FNG

| TB6612 Pin | Connected To | Net | Notes |
|---|---|-----|---|
| VM | Battery rail | +BATT | Motor power, 7.2–8.4 V — NOT buck output |
| VCC | Pico 3V3(OUT) | +3V3_PICO | Logic supply — 3.3 V only |
| GND | Common GND | GND | Both GND pins |
| PWMA | Pico GP2 | MOTOR_PWM1 | Left motor |
| AIN | Pico GP3 | MOTOR_DIR1 | Left direction |
| PWMB | Pico GP4 | MOTOR_PWM2 | Right motor |
| BIN | Pico GP5 | MOTOR_DIR2 | Right direction |
| STBY | 3V3 | — | Tied HIGH permanently |
| M1+ | Left motor + | M1P | Swap M1+/M1− to reverse |
| M1− | Left motor − | M1N | |
| M2+ | Right motor + | M2P | |
| M2− | Right motor − | M2N | Right motor wires physically reversed |

---

## Power Rails

| Rail | Source | Voltage | Consumers |
|---|---|---|---|
| +BATT | Battery through switch | 7.2–8.4 V | TB6612 VM only |
| +5V | Buck converter | 5.00 V ±0.1 V | ESP32 VIN, Pico VSYS, Sharp IR VCC |
| +3V3_ESP | ESP32 internal | 3.3 V | RC522 VCC |
| +3V3_PICO | Pico internal | 3.3 V | TB6612 VCC |
| GND | Battery − | 0 V | All modules (common bus) |

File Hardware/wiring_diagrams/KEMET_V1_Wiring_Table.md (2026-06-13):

# KEMET Robot V1 — Pin-to-Pin Wiring Table

Prototype V1 | Autonomous Maze-Solving Robot  
Status: **Development / No Encoders / Open-Loop Motor Control**

---

## 1. Power Subsystem

| From | To | Wire / Note |
|---|----|---|
| 2S Li-ion Battery `[+]` | Main Power Switch IN | Red, 20 AWG min |
| Main Power Switch OUT | 5 V Buck Converter IN | Red |
| Main Power Switch OUT | TB6612FNG `VM` | Red — motor power rail (~7.2–8.4 V) |
| 5 V Buck Converter OUT `[+]` | ESP32 `VIN` | Red |
| 5 V Buck Converter OUT `[+]` | Raspberry Pi Pico `VSYS` | Red |
| 5 V Buck Converter OUT `[+]` | All Sharp IR `VCC` (×4) | Red — 5 V sensor supply |
| 5 V Buck Converter OUT `[+]` | VL53L1X `VIN` | Red — 5 V if breakout has regulator |
| 2S Li-ion Battery `[−]` | Common GND bus | Black, 20 AWG min |
| Buck Converter GND | Common GND bus | Black |

> **⚠ VERIFY** buck converter output = **5.00 V ±0.1 V** with a multimeter **before** connecting any board.

---

## 2. ESP32 — Sensing & Navigation

### 2a. Power

| ESP32 Pin | Connects To | Net |
|---|---|-----|
| `VIN` | 5 V Buck OUT | `+5V` |
| `3V3` | RC522 `3.3V`, internal reference | `+3V3_ESP` |
| `GND` | Common GND | `GND` |

### 2b. SPI — RC522 RFID (3.3 V ONLY)

| ESP32 GPIO | RC522 Pin | Net | Direction |
|---|---|-----|---|
| `GPIO5` | `SDA / SS` | `RFID_SS` | ESP32 → RC522 |
| `GPIO18` | `SCK` | `SPI_SCK` | ESP32 → RC522 |
| `GPIO23` | `MOSI` | `SPI_MOSI` | ESP32 → RC522 |
| `GPIO19` | `MISO` | `SPI_MISO` | RC522 → ESP32 |
| `GPIO4` | `RST` | `RFID_RST` | ESP32 → RC522 |
| `3V3` | `3.3V` | `+3V3_ESP` | Power |
| `GND` | `GND` | `GND` | Power |

> **⚠ RC522 MUST be powered from 3.3 V ONLY. 5 V will permanently destroy it.**

### 2c. I2C — VL53L1X Time-of-Flight

| ESP32 GPIO | VL53L1X Pin | Net | Direction |
|---|---|-----|---|
| `GPIO21` | `SDA` | `I2C_SDA` | Bidirectional |
| `GPIO22` | `SCL` | `I2C_SCL` | ESP32 → ToF |
| `VIN` or `3V3` | `VIN` | `+5V` or `+3V3_ESP` | Power (check breakout) |
| `GND` | `GND` | `GND` | Power |

> I2C address: `0x29` (default). Use 3.3 V supply if breakout has no onboard regulator.

### 2d. ADC — Sharp IR Sensors

| ESP32 GPIO | Sensor | Net | Note |
|---|---|-----|---|
| `GPIO34` | Left Outer IR `OUT` | `IR_LO` | Input-only ADC pin |
| `GPIO35` | Left Inner IR `OUT` | `IR_LI` | Input-only ADC pin |
| `GPIO36` | Right Inner IR `OUT` | `IR_RI` | Input-only ADC pin |
| `GPIO39` | Right Outer IR `OUT` | `IR_RO` | Input-only ADC pin |

> GPIO 34/35/36/39 are **input-only** — no internal pull-up/pull-down.  
> All IR `VCC` → `+5V` rail.  All IR `GND` → Common GND.

### 2e. UART — to Raspberry Pi Pico

| ESP32 GPIO | Pico GP | Net | Direction |
|---|---|-----|---|
| `GPIO17` (TX) | `GP1` (RX) | `UART_TX` | ESP32 → Pico |
| `GPIO16` (RX) | `GP0` (TX) | `UART_RX` | Pico → ESP32 |
| `GND` | `GND` | `GND` | Shared reference |

> Both devices are 3.3 V logic. No level shifter required.  
> Recommended baud rate: **115200**.

---

## 3. Raspberry Pi Pico — Motor Control

### 3a. Power

| Pico Pin | Connects To | Net |
|---|---|-----|
| `VSYS` | 5 V Buck OUT | `+5V` |
| `3V3(OUT)` | TB6612FNG `VCC` | `+3V3_PICO` |
| `GND` | Common GND + TB6612 GND | `GND` |

### 3b. UART — to ESP32

| Pico GP | ESP32 GPIO | Net | Direction |
|---|---|-----|---|
| `GP0` (TX) | `GPIO16` (RX) | `UART_RX` | Pico → ESP32 |
| `GP1` (RX) | `GPIO17` (TX) | `UART_TX` | ESP32 → Pico |

### 3c. Motor Control — to TB6612FNG

| Pico GP | TB6612 Pin | Net | Function |
|---|---|-----|---|
| `GP2` | `PWM1` | `MOTOR_PWM1` | Left motor speed |
| `GP3` | `DIR1` | `MOTOR_DIR1` | Left motor direction |
| `GP4` | `PWM2` | `MOTOR_PWM2` | Right motor speed |
| `GP5` | `DIR2` | `MOTOR_DIR2` | Right motor direction |
| `3V3(OUT)` | `VCC` | `+3V3_PICO` | TB6612 logic supply |
| `GND` | `GND` | `GND` | Common GND |

> Recommended PWM frequency: **10–20 kHz** to avoid audible motor whine.

---

## 4. TB6612FNG Motor Driver

### 4a. Power

| TB6612 Pin | Connects To | Net | Note |
|---|---|-----|---|
| `VM` | Battery rail (switch output) | `+BATT` | Motor power, 7.2–8.4 V |
| `VCC` | Pico `3V3(OUT)` | `+3V3_PICO` | Logic supply — 3.3 V ONLY |
| `GND` | Common GND | `GND` | Both GND pins |

### 4b. Control Inputs

| TB6612 Pin | Pico GP | Net |
|---|---|-----|
| `PWM1` | `GP2` | `MOTOR_PWM1` |
| `DIR1` | `GP3` | `MOTOR_DIR1` |
| `PWM2` | `GP4` | `MOTOR_PWM2` |
| `DIR2` | `GP5` | `MOTOR_DIR2` |
| `STBY` | `3V3` or `VCC` | Tie HIGH to enable driver |

### 4c. Motor Outputs

| TB6612 Pin | Motor | Net |
|---|---|-----|
| `M1+` | Left N20 motor `[+]` | `M1P` |
| `M1−` | Left N20 motor `[−]` | `M1N` |
| `M2+` | Right N20 motor `[+]` | `M2P` |
| `M2−` | Right N20 motor `[−]` | `M2N` |

> Swap `M1+`/`M1−` (or `M2+`/`M2−`) to reverse a motor's spin direction.

---

## 5. Sharp IR Sensors (×4)

All four sensors share the same wiring pattern:

| IR Sensor Pin | Connects To | Net |
|---|---|-----|
| `VCC` | 5 V Buck OUT | `+5V` |
| `GND` | Common GND | `GND` |
| `OUT` | See table below | sensor-specific |

| Sensor | OUT → ESP32 | Net |
|---|---|-----|
| Left Outer | `GPIO34` | `IR_LO` |
| Left Inner | `GPIO35` | `IR_LI` |
| Right Inner | `GPIO36` | `IR_RI` |
| Right Outer | `GPIO39` | `IR_RO` |

**Decoupling (mandatory per sensor):**
- 10 µF electrolytic capacitor: VCC to GND, placed **close to sensor**
- 0.1 µF ceramic capacitor: VCC to GND, in parallel with electrolytic

---

## 6. Net Name Reference

| Net Name | Description |
|---|---|
| `+BATT` | Raw battery rail post-switch (~7.2–8.4 V) |
| `+5V` | Regulated 5 V from buck converter |
| `+3V3_ESP` | ESP32 3.3 V output (powers RC522) |
| `+3V3_PICO` | Pico 3.3 V output (powers TB6612 logic) |
| `GND` | Common ground (all modules share this) |
| `UART_TX` | ESP32 GPIO17 TX → Pico GP1 RX |
| `UART_RX` | Pico GP0 TX → ESP32 GPIO16 RX |
| `IR_LO` | Left Outer IR analog output → GPIO34 |
| `IR_LI` | Left Inner IR analog output → GPIO35 |
| `IR_RI` | Right Inner IR analog output → GPIO36 |
| `IR_RO` | Right Outer IR analog output → GPIO39 |
| `I2C_SDA` | I2C data — GPIO21 ↔ VL53L1X SDA |
| `I2C_SCL` | I2C clock — GPIO22 → VL53L1X SCL |
| `SPI_SCK` | SPI clock — GPIO18 → RC522 SCK |
| `SPI_MOSI` | SPI MOSI — GPIO23 → RC522 MOSI |
| `SPI_MISO` | SPI MISO — GPIO19 ← RC522 MISO |
| `RFID_SS` | RC522 chip-select — GPIO5 → RC522 SS |
| `RFID_RST` | RC522 reset — GPIO4 → RC522 RST |
| `MOTOR_PWM1` | Left motor PWM — Pico GP2 → TB6612 PWM1 |
| `MOTOR_DIR1` | Left motor dir — Pico GP3 → TB6612 DIR1 |
| `MOTOR_PWM2` | Right motor PWM — Pico GP4 → TB6612 PWM2 |
| `MOTOR_DIR2` | Right motor dir — Pico GP5 → TB6612 DIR2 |
| `M1P` | Left motor + terminal |
| `M1N` | Left motor − terminal |
| `M2P` | Right motor + terminal |
| `M2N` | Right motor − terminal |

---

## 7. Pre-Power Checklist

- [ ] Buck converter output measured = 5.00 V ±0.1 V (no boards connected)
- [ ] All GNDs verified continuous to battery negative (multimeter continuity)
- [ ] RC522 VCC wire confirmed connected to ESP32 3V3 — NOT the 5V rail
- [ ] TB6612 VM wire confirmed connected to battery rail — NOT buck output
- [ ] TB6612 VCC wire confirmed connected to Pico 3V3 — NOT 5V rail
- [ ] TB6612 STBY pin tied HIGH (3V3 or VCC)
- [ ] All IR sensor decoupling caps installed
- [ ] UART TX/RX cross-connected (ESP32 TX → Pico RX, Pico TX → ESP32 RX)
- [ ] No encoder wires (V1 — open-loop only)

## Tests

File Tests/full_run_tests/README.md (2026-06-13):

# Full Run Tests

Purpose: test the complete robot behaviour through a maze section or full maze — RFID reading, movement execution, and wall avoidance combined.

## Prerequisites

All of the following must have passing test logs before a full run test:
- [ ] Straight line tests pass (`Tests/straight_line_tests/`)
- [ ] Turn calibration pass (`Tests/turn_tests/`)
- [ ] RFID UID mapping complete (`Tests/rfid_tests/`)
- [ ] Wall following stable (`Tests/wall_following_tests/`)

## What to Record Per Session

| Field | Description |
|---|---|
| Date | YYYY-MM-DD |
| Battery voltage | At start and end |
| Maze layout | Sketch or photo of the test course |
| Commands issued (from RFID) | Sequence of commands the robot received |
| Commands executed | What the robot actually did |
| Wall contacts | Count and location |
| Completion | Yes / No / Partial |
| Time | Seconds from START to STOP |

## File Naming

`YYYY-MM-DD_full_run_test.md`

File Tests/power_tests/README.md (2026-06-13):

# Power Tests

Purpose: verify the power system stays stable under motor load, measure current draw, and confirm voltage rails do not sag during operation.

## What to Record Per Session

| Field | Description |
|---|---|
| Date | YYYY-MM-DD |
| Battery voltage at rest | V |
| Battery voltage under motor load | V (both motors running at BASE_PWM) |
| Buck converter output at rest | V |
| Buck converter output under motor load | V |
| Current draw — motors only | A |
| Current draw — full system | A |
| ESP32/Pico resets during run | yes / no |

## Pass Criteria

- Buck output stays above 4.85 V under full motor load.
- No ESP32 or Pico resets during a 30-second run.
- Battery voltage under load does not drop below 6.8 V (2S cutoff threshold).

## File Naming

`YYYY-MM-DD_power_test.md`

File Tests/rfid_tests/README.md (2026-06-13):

# RFID Tests

Purpose: verify the RC522 can reliably read all navigation cards and map UIDs to the correct commands.

## What to Record Per Session

| Field | Description |
|---|---|
| Date | YYYY-MM-DD |
| Card | Which tag (START / STOP / LEFT / RIGHT / DEAD END) |
| UID read | Hex bytes printed by firmware |
| Read distance | mm from sensor to card |
| Read speed | Stationary / slow / fast |
| Success rate | Reads / attempts |

## Required Before Navigation Testing

- [ ] All card UIDs measured and recorded
- [ ] UID → command lookup table complete in firmware
- [ ] Read tested at robot's normal driving speed

## File Naming

`YYYY-MM-DD_rfid_uid_mapping.md` or `YYYY-MM-DD_rfid_speed_test.md`

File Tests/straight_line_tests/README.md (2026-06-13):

# Straight Line Tests

Purpose: verify the robot can drive one corridor section without touching walls and without accumulated drift.

## What to Record Per Session

| Field | Description |
|---|---|
| Date | YYYY-MM-DD |
| Battery voltage | Measured at test start |
| Surface | OSB / tile / smooth laminate |
| `BASE_PWM` | Value used |
| `STRAIGHT_PULSES` | Value used |
| Left encoder pulses | Actual count at stop |
| Right encoder pulses | Actual count at stop |
| Measured distance | Physical tape measurement |
| Lateral drift | cm left or right of start heading |
| Wall contact | yes / no |

## Pass Criteria

- Endpoint within 3 cm of start heading after one corridor length.
- No wall contact.
- Left and right encoder counts differ by ≤ 3 pulses.

## File Naming

`YYYY-MM-DD_straight_calibration.md`

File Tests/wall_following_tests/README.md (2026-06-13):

# Wall Following Tests

Purpose: verify IR sensor readings are accurate and that the lateral correction loop keeps the robot centred in the corridor.

## What to Record Per Session

| Field | Description |
|---|---|
| Date | YYYY-MM-DD |
| Battery voltage | Measured at test start |
| Surface | OSB / tile |
| Left IR raw ADC | Value at known distances |
| Right IR raw ADC | Value at known distances |
| Correction threshold | PWM deadband used |
| Result | Robot stayed centred / drifted / oscillated |

## Pass Criteria

- Robot stays within ±2 cm of corridor centre over 1 m straight run.
- No wall contact.
- No oscillation (side-to-side overcorrection).

## File Naming

`YYYY-MM-DD_wall_following_test.md`

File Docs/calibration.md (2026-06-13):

# Calibration

## Purpose

Records the measured and tuned constants that control all robot movement. Every firmware version must start from the last stable values in this file.

## Current Motor Constants

| Constant | Current Value | Meaning |
|---|---:|---|
| `BASE_PWM` | 160 | Straight drive speed (0–255) |
| `TURN_PWM` | 130 | Turn speed (lower = more accurate) |
| `STRAIGHT_PULSES` | 70 | One forward step (~23 cm) |
| `TURN_90_PULSES` | 28 | Initial 90° pivot value (calculated, not yet tuned) |

These values are defined at the top of `Code/Pico/motor_control/phase1_motor_calibration.ino`.

## Measured Physical Parameters

| Parameter | Value | Source |
|---|---:|---|
| Wheel diameter | 37 mm | Measured on robot |
| Wheel-to-wheel distance (L) | 115 mm | Measured on robot |
| Encoder pulses per revolution | 35 | Measured (HC-89, RISING edge) |
| 90° pulse target (calculated) | 27.2 → start at 28 | π × L/4 ÷ (π × d) × PPR |

Calculation:
```
Wheel circumference  = π × 37 mm = 116.24 mm
Arc for 90° pivot    = π × 115 mm / 4 = 90.32 mm
Revolutions needed   = 90.32 / 116.24 = 0.777
Pulse target         = 0.777 × 35 = 27.2  → start at 28
```

## Left vs Right Turn Calibration

Left and right turns must be calibrated separately. A single `TURN_90_PULSES` value is not sufficient if the robot consistently overshoots one direction and undershoots the other due to chassis asymmetry, gear wear, or mounting differences.

| Direction | Calibrated Pulse Count | Last Tested | Notes |
|---|---:|---|---|
| Left 90° | TBD | — | |
| Right 90° | TBD | — | |

## Straight Line Drift Correction

Software trim applied inside `goStraight()` when one encoder leads the other by more than 2 pulses:

```cpp
if (pulseL > pulseR + 2) {
    analogWrite(PWM_L, BASE_PWM - 15);  // slow down leading wheel
} else if (pulseR > pulseL + 2) {
    analogWrite(PWM_R, BASE_PWM - 15);
}
```

Trim offset of 15 is a starting point. Increase if still drifting, decrease if oscillating.

## Calibration Procedure

See [`Docs/testing_protocol.md`](testing_protocol.md) for the step-by-step test sequence.

Short version:
1. Verify encoder counting (35 pulses per manual wheel revolution).
2. Confirm forward direction.
3. Tune `BASE_PWM` and drift trim for straight movement.
4. Tune `TURN_90_PULSES` for right turns.
5. Tune separately for left turns if asymmetric.
6. Run 4-turn heading-return test (R→R→L→L) and measure accumulated error.

## Locked Values After Calibration

Fill in after successful calibration sessions:

| Parameter | Locked Value | Surface | Date |
|---|---:|---|---|
| `BASE_PWM` | | | |
| `TURN_PWM` | | | |
| `STRAIGHT_PULSES` | | | |
| `LEFT_90_PULSES` | | | |
| `RIGHT_90_PULSES` | | | |

## Test Logs

See `Tests/turn_tests/` and `Tests/straight_line_tests/` for dated test session files.

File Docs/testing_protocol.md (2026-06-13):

# Testing Protocol

## Purpose

Defines the standard test procedure for each subsystem and the format for recording test results in `Tests/`.

## Test Log Format

Every test session gets one file in the appropriate subfolder under `Tests/`. File name: `YYYY-MM-DD_description.md`.

```md
# [Test Name]

Date: YYYY-MM-DD
Robot version: Prototype V1
Battery voltage: ___ V
Firmware commit: (git short hash)
Surface: (OSB / floor tile / smooth floor / carpet)
Test type: (describe exactly what is being tested)

## Setup

(Describe any physical setup, markings, tape lines used)

## Results

| Trial | Input / Target | Observed | Error | Notes |
|-------|---------------|---------|-------|-------|
| 1 | | | | |
| 2 | | | | |
| 3 | | | | |

## Conclusion

(What was learned. What to change next.)
```

## Phase 1 Test Sequence

Run these in order. Do not proceed to the next test until the current one passes consistently.

### 1. Encoder count verification

- Comment out all motor calls.
- Print `pulseL` and `pulseR` to Serial.
- Manually spin each wheel one full revolution.
- **Pass:** both counters increment by 35 ±2.

### 2. Forward direction

- Run sketch, observe straight segment only.
- **Pass:** robot moves forward (away from the start line).

### 3. Straight drift

- Drive straight for `STRAIGHT_PULSES = 70` pulses on a 2-metre tile floor.
- **Pass:** robot endpoint is within 3 cm of the start heading.

### 4. Right turn accuracy

- Mark heading with tape. Run one right turn.
- **Pass:** final heading is within ±5° of 90°.

### 5. Left turn accuracy

- Same as above for left turn.
- **Pass:** final heading is within ±5° of 90°.

### 6. 4-turn heading return

- Run R→R→L→L sequence.
- **Pass:** robot returns to within ±10° of starting heading.

## Where to Save Results

| Test type | Folder |
|---|---|
| Straight distance | `Tests/straight_line_tests/` |
| 90° turns | `Tests/turn_tests/` |
| RFID reading | `Tests/rfid_tests/` |
| Wall following | `Tests/wall_following_tests/` |
| Full maze run | `Tests/full_run_tests/` |

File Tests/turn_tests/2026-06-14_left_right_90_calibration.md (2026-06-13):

# 90° Turn Calibration — 2026-06-14

Robot version: Prototype V2
Battery voltage: ___ V
Surface: ___
`BASE_PWM`: 160
`TURN_PWM`: 130
`TURN_90_PULSES`: 28
Firmware commit: ___

## Setup

Marked heading with tape on floor. Robot placed on tape line. Observed turn by eye and measured deviation from tape with a protractor / angle reference.

## Results

| Trial | Direction | Target | Actual | Error | Notes |
|---:|---|---:|---:|---:|---|
| 1 | Right | 90° | | | |
| 2 | Right | 90° | | | |
| 3 | Right | 90° | | | |
| 4 | Left | 90° | | | |
| 5 | Left | 90° | | | |
| 6 | Left | 90° | | | |

## 4-Turn Heading Return

Run sequence: R → R → L → L  
Expected final heading: same as start  
Actual heading deviation: ___°

## Conclusion

TBD after testing.

## Next Change

TBD — increase/decrease `TURN_90_PULSES`, or split into separate left/right constants.

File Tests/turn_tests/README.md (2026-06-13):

# Turn Tests

Each file in this folder is one test session log following the format in [`Docs/testing_protocol.md`](../../Docs/testing_protocol.md).

File naming: `YYYY-MM-DD_description.md`

Example result table:

| Trial | Target | Actual | Error | Notes |
|---|---|---|---|---|
| 1 | 90° | 93° | +3° | slight overshoot |
| 2 | 90° | 92° | +2° | stable |
| 3 | 90° | 94° | +4° | wheel slip on smooth tile |

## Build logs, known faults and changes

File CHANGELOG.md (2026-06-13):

# Changelog

## [Unreleased]

### Added
- Full project documentation structure (`Docs/`, `Tests/`, `Hardware/`, `Media/`)
- `Docs/system_architecture.md` — dual-controller design and communication protocol
- `Docs/competition_rules_summary.md` — engineering-relevant competition constraints
- `Docs/hardware_design.md` — component selection and power architecture
- `Docs/electronics_power_system.md` — voltage rails and pre-power checklist
- `Docs/motor_control.md` — Pico motor control, calibration parameters, known issues
- `Docs/rfid_navigation.md` — RC522 integration and UID command mapping
- `Docs/wall_following.md` — Sharp IR and ToF sensor wall detection
- `Docs/calibration.md` — step-by-step Phase 1 motor calibration guide
- `Docs/testing_protocol.md` — standard test log format and Phase 1 test sequence
- `Docs/troubleshooting.md` — symptom → cause → fix table for all subsystems
- `Hardware/bill_of_materials.md` — full BOM for Prototype V1
- GitHub issue templates and PR template
- `CONTRIBUTING.md` — commit style and file location guide

### Changed
- `README.md` restructured to short overview with links to `Docs/`
- `pico/` moved to `Code/Pico/motor_control/`
- `docs/` moved to `Docs/`
- `schematics/` moved to `Hardware/schematics/` and `Hardware/wiring_diagrams/`

## [0.1.0] — 2026-06

### Added
- Prototype V1 assembled
- `pico/phase1_motor_calibration/` — encoder-based straight and 90° turn firmware
- `schematics/KEMET_V1_Schematic.json` — EasyEDA schematic for Prototype V1
- `schematics/KEMET_V1_Wiring_Table.md` — full pin-to-pin wiring table
- `docs/CALIBRATION_GUIDE.md` — Phase 1 calibration procedure

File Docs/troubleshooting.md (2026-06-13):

# Troubleshooting

## Motor Issues

| Symptom | Likely Cause | Fix |
|---|---|-----|
| Motors do not move at all | TB6612 STBY not HIGH | Tie STBY to 3.3 V |
| Motors do not move at all | TB6612 VM not connected | Connect VM to battery rail |
| Motors do not move at all | Wrong PWM pin | Check GP2 / GP4 wiring |
| One motor does not move | One channel wiring error | Verify PWM and DIR for that channel |
| Robot moves backward | FWD/BWD direction wrong | Swap FWD/BWD defines in sketch |
| Robot spins forever | Encoder wire disconnected | Check GP6 / GP7 and HC-89 power |
| Robot curves heavily | Encoder not counting | Verify encoder wiring and power |
| Robot oscillates in straight line | Drift trim too high | Reduce trim offset from 15 |

## Encoder Issues

| Symptom | Likely Cause | Fix |
|---|---|-----|
| Counter never increments | ISR not triggering | Verify attachInterrupt() and pin number |
| Counter jumps by 2–4 per slot | Double-triggering | Add 100 nF cap from OUT to GND near sensor |
| Very different counts (L=30, R=5) | One encoder misaligned | Realign HC-89 disc with sensor slot |
| Counts stop mid-move | Loose encoder wire | Reseat connector |

## Power Issues

| Symptom | Likely Cause | Fix |
|---|---|-----|
| ESP32 / Pico resets during motor run | Buck cannot supply peak motor current | Check buck rated current; add bypass cap |
| RC522 not detected | Powered from 5 V rail | Move VCC wire to ESP32 3V3 pin |
| IR sensor reads garbage | Missing decoupling caps | Add 10 µF + 0.1 µF per sensor |
| Erratic behaviour after wiring change | Missing GND connection | Verify all modules share common GND |

## UART / Communication Issues

| Symptom | Likely Cause | Fix |
|---|---|-----|
| No data received | TX/RX not crossed | ESP32 TX → Pico RX; Pico TX → ESP32 RX |
| Garbled data | Baud rate mismatch | Both sides must be set to 115200 |
| Commands lost | No flow control | Add software ACK; Pico replies OK before next command |

## RFID Issues

| Symptom | Likely Cause | Fix |
|---|---|-----|
| RC522 not initialised | SPI wiring error | Check GPIO5/18/23/19/4 wiring |
| Card not detected | RC522 on wrong voltage | Must be 3.3 V — check with multimeter |
| UID reads as all zeros | Read too fast | Add `PICC_HaltA()` + delay before next read |

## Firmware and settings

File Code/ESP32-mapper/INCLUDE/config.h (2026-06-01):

#pragma once
//  config.h — ESP32 Maze Mapper
//  Single source of truth for all pins, bus settings and
//  tuning constants. Edit ONLY this file.

//  VSPI bus — RC522 RFID 
//  (VSPI hardware defaults: SCK=18 MOSI=23 MISO=19)
static constexpr int  RFID_SS_PIN   = 5;
static constexpr int  RFID_RST_PIN  = 4;
// SCK=18, MOSI=23, MISO=19  (hardware VSPI — no define needed)

//  HSPI bus — SPI to Pico (ESP32 = master) 
static constexpr int  PICO_SCK_PIN  = 14;   // ESP32 GPIO14 → Pico GP18
static constexpr int  PICO_MOSI_PIN = 13;   // ESP32 GPIO13 → Pico GP19
static constexpr int  PICO_MISO_PIN = 32;   // ESP32 GPIO32 ← Pico GP16
static constexpr int  PICO_CS_PIN   = 33;   // ESP32 GPIO33 → Pico GP17
static constexpr long PICO_SPI_FREQ = 1000000; // 1 MHz — safe for wires

//  I2C — VL53L1X ToF
//  (I2C hardware defaults: SDA=21, SCL=22)
static constexpr uint16_t TOF_WALL_MM    = 150;  // wall if distance < this
static constexpr uint32_t TOF_TIMEOUT_MS = 500;

//  IR sensors  Sharp analog (GPIO 34/35/36/39 input-only) 
static constexpr int  IR_LEFT_OUTER  = 34;
static constexpr int  IR_LEFT_INNER  = 35;
static constexpr int  IR_RIGHT_INNER = 36;
static constexpr int  IR_RIGHT_OUTER = 39;
// ADC threshold: readings below this = obstacle detected
// Sharp GP2Y0A21 at ~3 cm gives ~2500 ADC counts (12-bit)
static constexpr int  IR_THRESHOLD   = 1800;

//  Special RFID tag UIDs
//  Read your tags first with MFRC522 DumpInfo, paste hex here
static constexpr char START_UID[]   = "A1B2C3D4";
static constexpr char FINISH_UID[]  = "DEADBEEF";

//  Timing
static constexpr uint32_t TAG_SETTLE_MS  = 300;  // pause before reading sensors
static constexpr uint32_t INTER_CMD_MS   = 80;
static constexpr uint32_t LOOP_DELAY_MS  = 40;

//  Map
static constexpr uint8_t  MAX_NODES      = 64;

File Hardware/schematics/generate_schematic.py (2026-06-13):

#!/usr/bin/env python3
"""
KEMET Robot V1 - EasyEDA Standard Edition Schematic Generator
=============================================================
Run:    python generate_schematic.py
Output: KEMET_V1_Schematic.json   (import into EasyEDA Standard via File → Open)

Layout (canvas 2400 × 1720 px, 10 px/grid):
  Block 1  Power Subsystem          top-left
  Block 2  ESP32 Sensing/Nav        left column
  Block 3  Raspberry Pi Pico        bottom-left
  Block 4  TB6612FNG Motor Driver   bottom-centre
  Block 5  Sensor Subsystem         right area (4× IR, ToF, RFID)
  Block 6  UART Bridge              centre floating
  Block 7  Motor Outputs            bottom-right
  Notes    Warning strip            bottom
  Title    Title block              very bottom
"""

import json

# ---------------------------------------------------------------------------
# Low-level shape helpers
# ---------------------------------------------------------------------------
shapes = []
_gid = [1]

def _gge():
    g = f"gge{_gid[0]}"
    _gid[0] += 1
    return g

def ann(x, y, text, color="#000000", size=7, bold=False, rot=0):
    """Non-electrical text annotation."""
    w = "bold" if bold else "normal"
    shapes.append(
        f"ANNOTATION~{x}~{y}~{rot}~{text}~{color}~Arial~{size}~{w}~normal~comment~{_gge()}"
    )

def netlabel(x, y, net, rot=0):
    """Electrical net label – connects same-name labels."""
    shapes.append(
        f"NETLABEL~{x}~{y}~{rot}~{net}~#0000FF~Arial~7~bold~normal~comment~{_gge()}"
    )

def wire(x1, y1, x2, y2, color="#880000"):
    """Electrical wire segment."""
    shapes.append(f"WIRE~{x1} {y1} {x2} {y2}~{color}~1~0~none~{_gge()}")

def junction(x, y):
    shapes.append(f"JUNCTION~{x}~{y}~#880000~{_gge()}")

def polyline(pts_flat, color="#000000", lw=1, fill="none"):
    """Non-electrical polyline.  pts_flat = [(x,y), ...]"""
    pts = " ".join(f"{x} {y}" for x, y in pts_flat)
    shapes.append(f"POLYLINE~{pts}~{color}~{lw}~0~{fill}~{_gge()}")

def rect_poly(x, y, w, h, color="#003366", lw=2, fill="none"):
    """Draw rectangle as closed polyline (non-electrical)."""
    polyline([(x,y),(x+w,y),(x+w,y+h),(x,y+h),(x,y)], color=color, lw=lw, fill=fill)

def title_bar(x, y, w, title, bg="#003366", fg="#FFFFFF"):
    """Filled title bar + white text."""
    rect_poly(x, y, w, 22, color=bg, lw=0, fill=bg)
    ann(x+5, y+5, title, color=fg, size=8, bold=True)

def block(x, y, w, h, title, border="#003366"):
    """Module block: border rectangle + filled title bar."""
    rect_poly(x, y, w, h, color=border, lw=2)
    title_bar(x, y, w, title, bg=border)

# ---------------------------------------------------------------------------
# Higher-level helpers
# ---------------------------------------------------------------------------
STUB = 30   # wire stub length in px

def pin_r(bx_right, py, label, net=None):
    """Pin stub + label on RIGHT edge of a block; optional net label outside."""
    wire(bx_right, py, bx_right + STUB, py)
    ann(bx_right - len(label)*4 - 4, py - 7, label, size=6)
    if net:
        netlabel(bx_right + STUB + 4, py - 5, net)

def pin_l(bx_left, py, label, net=None):
    """Pin stub + label on LEFT edge of a block; optional net label outside."""
    wire(bx_left - STUB, py, bx_left, py)
    ann(bx_left + 3, py - 7, label, size=6)
    if net:
        netlabel(bx_left - STUB - 65, py - 5, net)

def section_hdr(x, y, text, color="#004400"):
    ann(x, y, f"── {text} ──", color=color, size=6, bold=True)


# ===========================================================================
# BLOCK 1 — POWER SUBSYSTEM
# ===========================================================================
BX1, BY1, BW1, BH1 = 60, 50, 370, 240
block(BX1, BY1, BW1, BH1, "1. POWER SUBSYSTEM", border="#003366")

ann(BX1+10, BY1+32,  "2S Li-ion Battery Pack",           size=7, bold=True)
ann(BX1+10, BY1+48,  "7.2 V nom / 8.4 V max  (~1500 mAh suggested)", size=6, color="#555555")
ann(BX1+10, BY1+68,  "Battery [−]  ──►  Common GND",      size=6)
ann(BX1+10, BY1+84,  "Battery [+]  ──►  Main Power Switch",size=6)
ann(BX1+10, BY1+100, "Switch OUT   ──►  5 V Buck Converter IN",   size=6)
ann(BX1+10, BY1+116, "Switch OUT   ──►  TB6612 VM (motor rail)",   size=6)
ann(BX1+10, BY1+136, "5 V Buck OUT ──►  ESP32 VIN",        size=6)
ann(BX1+10, BY1+152, "5 V Buck OUT ──►  Pico VSYS",        size=6)
ann(BX1+10, BY1+168, "5 V Buck OUT ──►  Sharp IR VCC (×4)", size=6)
ann(BX1+10, BY1+184, "5 V Buck OUT ──►  VL53L1X VIN",      size=6)
ann(BX1+10, BY1+204, "⚠  Measure buck output = 5.00 V ±0.1 V BEFORE connecting boards",
    color="#CC0000", size=6, bold=True)
ann(BX1+10, BY1+220, "⚠  ALL grounds share one common reference",
    color="#CC0000", size=6, bold=True)

# Power net stubs on right edge
for py, net in [(BY1+116, "+BATT"), (BY1+152, "+5V"), (BY1+204, "GND")]:
    wire(BX1+BW1, py, BX1+BW1+STUB, py)
    netlabel(BX1+BW1+STUB+4, py-5, net)


# ===========================================================================
# BLOCK 2 — ESP32
# ===========================================================================
BX2, BY2, BW2, BH2 = 60, 340, 370, 580
block(BX2, BY2, BW2, BH2, "2. ESP32 — Sensing / Navigation", border="#003366")

# Power
section_hdr(BX2+10, BY2+32, "Power")
pin_r(BX2+BW2, BY2+48,  "VIN (5 V in)",       "+5V")
pin_r(BX2+BW2, BY2+66,  "3V3 out",            "+3V3_ESP")
pin_r(BX2+BW2, BY2+84,  "GND",                "GND")

# SPI — RC522
section_hdr(BX2+10, BY2+106, "SPI  (RC522 RFID — 3.3 V ONLY)")
pin_r(BX2+BW2, BY2+122, "GPIO5   → RFID SS",  "RFID_SS")
pin_r(BX2+BW2, BY2+140, "GPIO18  → SPI SCK",  "SPI_SCK")
pin_r(BX2+BW2, BY2+158, "GPIO23  → SPI MOSI", "SPI_MOSI")
pin_r(BX2+BW2, BY2+176, "GPIO19  → SPI MISO", "SPI_MISO")
pin_r(BX2+BW2, BY2+194, "GPIO4   → RFID RST", "RFID_RST")

# I2C — VL53L1X
section_hdr(BX2+10, BY2+216, "I2C  (VL53L1X ToF)")
pin_r(BX2+BW2, BY2+232, "GPIO21  SDA",         "I2C_SDA")
pin_r(BX2+BW2, BY2+250, "GPIO22  SCL",         "I2C_SCL")

# UART — to Pico
section_hdr(BX2+10, BY2+272, "UART  (to Raspberry Pi Pico)")
pin_r(BX2+BW2, BY2+288, "GPIO17  TX → Pico RX","UART_TX")
pin_r(BX2+BW2, BY2+306, "GPIO16  RX ← Pico TX","UART_RX")

# ADC — Sharp IR
section_hdr(BX2+10, BY2+328, "ADC  (Sharp IR Sensors)")
pin_r(BX2+BW2, BY2+344, "GPIO34  ← IR Left Outer",  "IR_LO")
pin_r(BX2+BW2, BY2+362, "GPIO35  ← IR Left Inner",  "IR_LI")
pin_r(BX2+BW2, BY2+380, "GPIO36  ← IR Right Inner", "IR_RI")
pin_r(BX2+BW2, BY2+398, "GPIO39  ← IR Right Outer", "IR_RO")
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

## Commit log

2026-05-20 First prototype photo
    I designed and assembled the initial prototype, including soldering all electronic components together on a 10×15 cm universal PCB board. The project demonstrates the complete integration of the circ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
2026-06-13 docs: organize project as engineering documentation
    - Restructure repo into Code/, Hardware/, Docs/, Tests/, Media/
    - Move Pico firmware to Code/Pico/motor_control/
    - Move wiring table and schematics to Hardware/
    - Add full Docs/ suite: system architecture, competition rules, hardware
    design, power system, motor control, RFID navigation, wall following,
    calibration (migrated), testing protocol, troubleshooting
    - Add Hardware/bill_of_materials.md
    - Add GitHub issue templates (firmware bug, hardware issue, test result)
    - Add PR template and CONTRIBUTING.md
    - Add CHANGELOG.md
    - Rewrite README.md as short overview with links to Docs/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
    [generate_schematic.py, phase1_motor_calibration.ino]
2026-06-13 docs: add prototype v2 docs, calibration, tests, and repo structure fixes
    - Add Docs/calibration.md with current constants, calculation, and locked-value table
    - Add Docs/prototypes/prototype_v1.md and prototype_v2.md with engineering captions
    - Fix Docs/competition_rules_summary.md: wall height 15 cm, thickness 15 mm, OSB floor
    - Add Hardware/wiring_diagrams/prototype_v2_pin_map.md
    - Add Code/README.md and Hardware/README.md
    - Add LICENSE (MIT)
    - Move Photos/ to Media/photos/prototype_v1/ with descriptive filenames
    - Add Media/photos/prototype_v2/ placeholder (photos to be added manually)
    - Add Tests/ subdirectories: straight_line, rfid, wall_following, full_run, power
    - Add dated turn test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
2026-06-24 docs: rewrite README for recruiter clarity
    - Add architecture diagram showing ESP32/Pico UART split
    - Add capability table (what the robot does + how)
    - Add How to Run section with exact flash steps
    - Add repo structure tree with actual file contents
    - Move demo section to top
    - Restructure: demo → capabilities → architecture → hardware → how to run → status → docs
